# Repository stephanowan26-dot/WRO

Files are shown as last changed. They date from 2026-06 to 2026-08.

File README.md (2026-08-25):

# Ingeniería de Materiales — WRO Future Engineers 2026

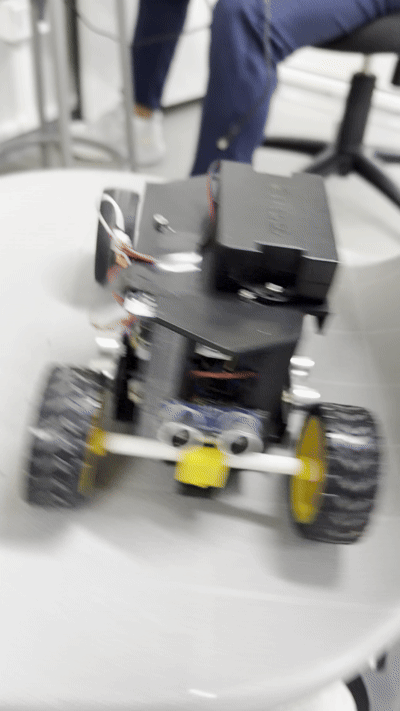
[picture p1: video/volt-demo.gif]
Volt en acción


**TEAM VOLT** — Lima, Perú — WRO Future Engineers 2026

Este repositorio documenta todo el proceso de ingeniería detrás de **"Volt"**, nuestro vehículo autónomo para la competencia WRO Future Engineers 2026: desde los primeros prototipos de cada componente hasta el modelo y código final de competencia.

---

## Tabla de Contenidos

1. [El Equipo](#el-equipo)
2. [Resumen del Vehículo](#resumen-del-vehículo)
3. [Contenido del Repositorio](#contenido-del-repositorio)
4. [Del Prototipo al Modelo Final](#del-prototipo-al-modelo-final)
5. [Arquitectura de Hardware](#arquitectura-de-hardware)
6. [Arquitectura de Software](#arquitectura-de-software)
7. [Errores que Encontramos y Cómo los Resolvimos](#errores-que-encontramos-y-cómo-los-resolvimos)
8. [Videos de Rendimiento](#videos-de-rendimiento)
9. [Instrucciones de Armado](#instrucciones-de-armado)
10. [Créditos](#créditos)
11. [Mejoras Futuras Posibles](#mejoras-futuras-posibles)

---

## El Equipo

**TEAM VOLT**

| Miembro | Edad |
|---|---|
| Carlos Jorge Rojas Ruiz | 17 |
| Stephano Wan Rong | 18 |
| Aadidev Nappanveetil Akhilesh | 17 |

<table>
  <tr>
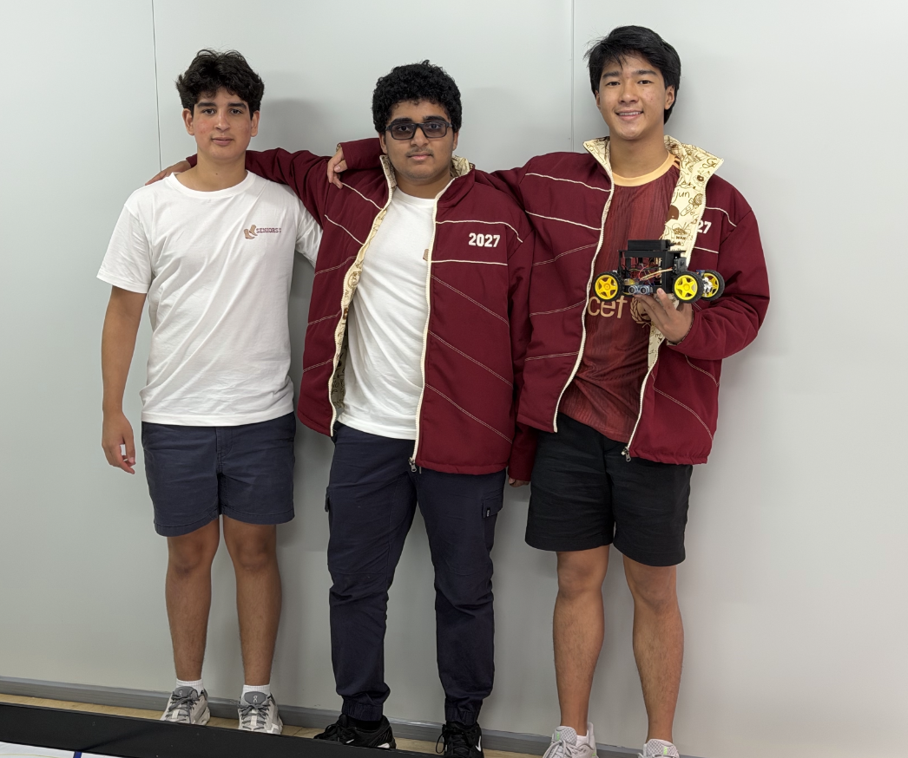
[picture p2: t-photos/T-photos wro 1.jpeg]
    <td align="center"><strong>Foto oficial</strong><br></td>
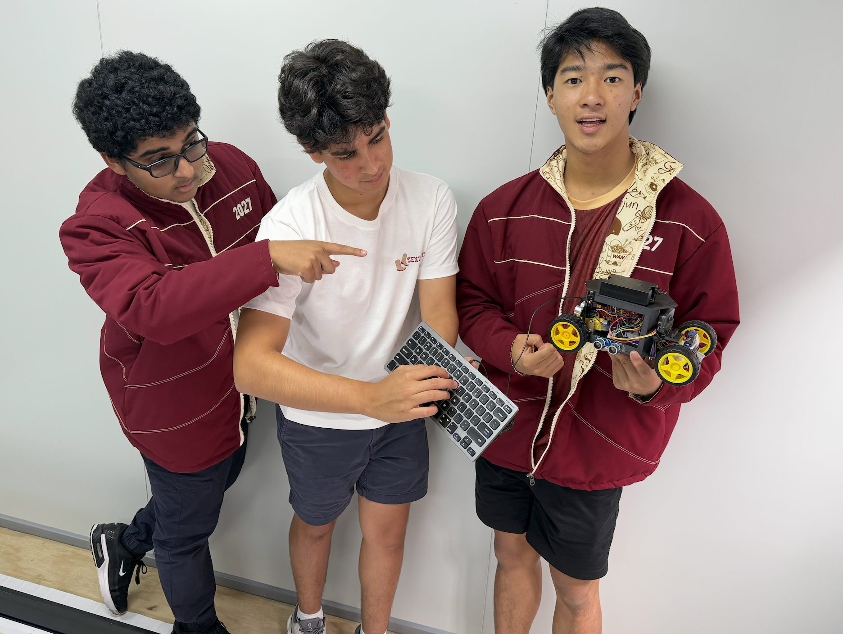
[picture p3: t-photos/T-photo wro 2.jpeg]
    <td align="center"><strong>Foto del equipo</strong><br></td>
  </tr>
</table>

---

## Resumen del Vehículo

"Volt" es un vehículo autónomo de cuatro ruedas, con tracción trasera y dirección delantera por servomotor, diseñado para navegar de forma completamente independiente un circuito de 3x3 metros, detectar y esquivar pilares de colores, y completar 3 vueltas de manera precisa y repetible, sin ninguna intervención humana.

El nombre "Volt" refleja la energía con la que el equipo abordó cada etapa: diseño mecánico, integración de sensores y programación del comportamiento autónomo.

**Dimensiones y peso** (dentro de las reglas de WRO 2026):
- Dimensiones máximas: 300 x 200 mm de planta, 300 mm de altura
- Peso total aproximado: bajo 1.5 kg

---

## Contenido del Repositorio

| Carpeta | Contenido |
|---|---|
| [`t-photos`](t-photos) | Fotos del equipo |
| [`v-photos`](v-photos) | Fotos del vehículo — prototipo y versión final, desde todos los lados |
| [`video`](video) | Enlaces a los videos de rendimiento en YouTube (Open y Obstacle Challenge) |
| [`schemes`](schemes) | Diagrama esquemático de los componentes electromecánicos y sus conexiones |
| [`src`](src) | Todo el código de control — desde prototipos individuales hasta el software final |
| [`models`](models) | Archivos STL para impresión 3D — chasis, ejes, soportes |
| [`material`](material) | Lista completa de materiales usados en el robot |

**Lee el README.md de cada carpeta para más detalle.**

---

## Del Prototipo al Modelo Final

Nuestro desarrollo fue iterativo: probamos cada componente por separado antes de integrarlo, y el chasis, el código y las fotos del vehículo pasaron por varias versiones hasta llegar al modelo final de competencia.

### Galería: Prototipo vs. Final

<table>
  <tr>
    <td align="center" colspan="2"><strong>Chasis</strong></td>
  </tr>
  <tr>
    <td align="center">Prototipo<br><em>(<a href="models/Prototype%20Chassis.stl">Prototype Chassis.stl</a>)</em></td>
    <td align="center">Final<br><em>(<a href="models/WRO%20Volt%20Chasis.stl">WRO Volt Chasis.stl</a>)</em></td>
  </tr>
  <tr>
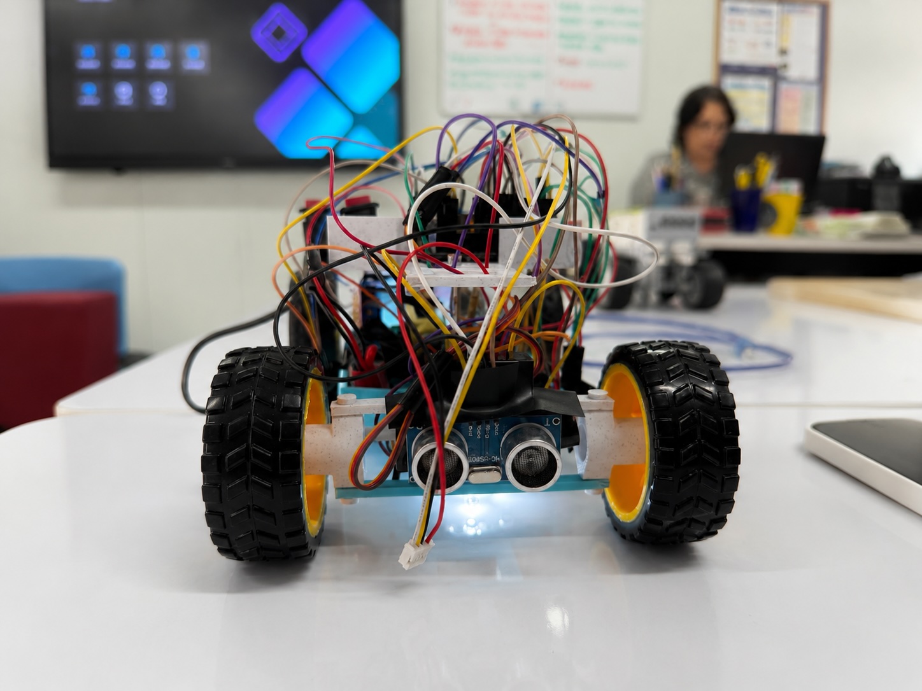
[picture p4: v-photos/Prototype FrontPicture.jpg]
    <td align="center"></td>
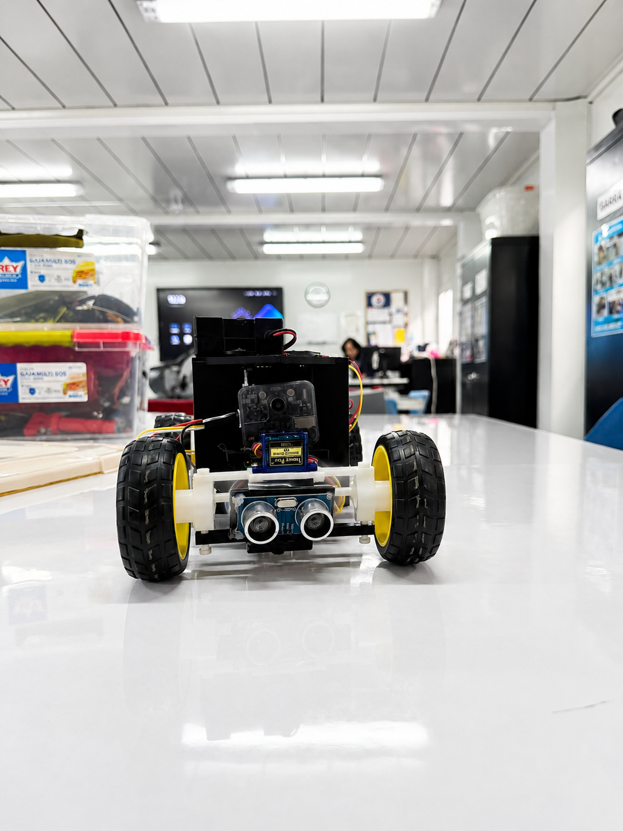
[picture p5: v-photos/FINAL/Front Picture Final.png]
    <td align="center"></td>
  </tr>
  <tr>
    <td align="center"></td>
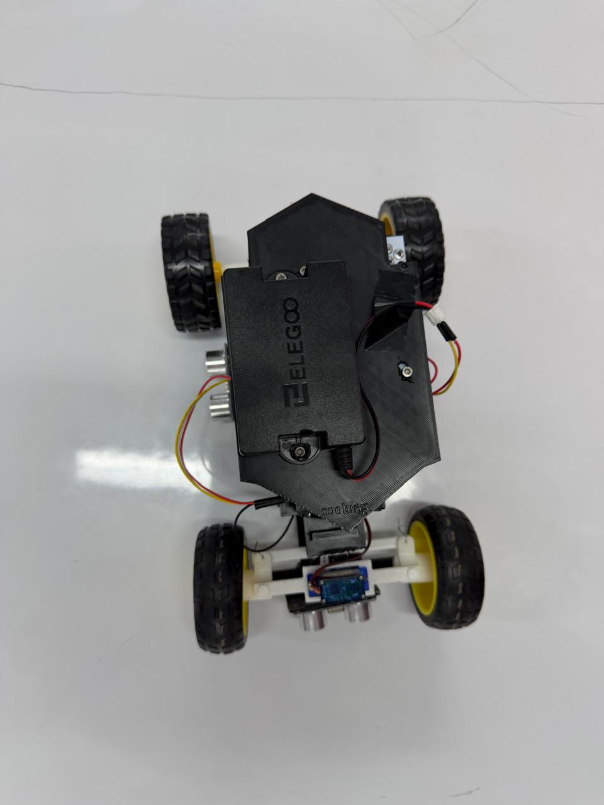
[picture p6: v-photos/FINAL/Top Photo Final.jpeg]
    <td align="center"></td>
  </tr>
  <tr>
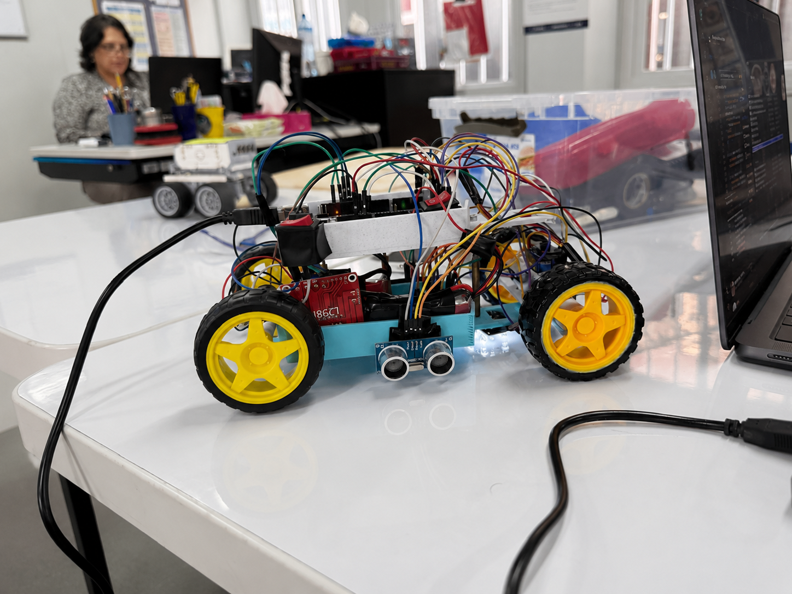
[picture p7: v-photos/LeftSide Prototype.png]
    <td align="center"></td>
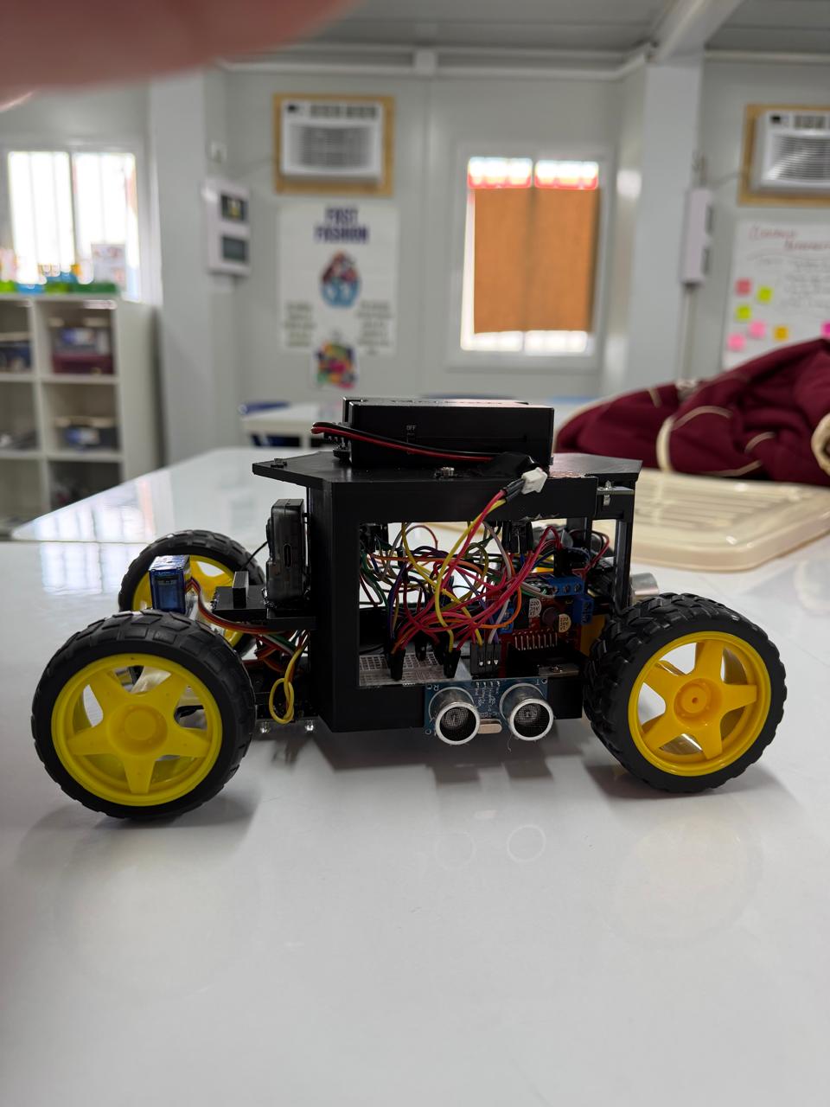
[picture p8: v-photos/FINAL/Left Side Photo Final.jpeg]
    <td align="center"></td>
  </tr>
  <tr>
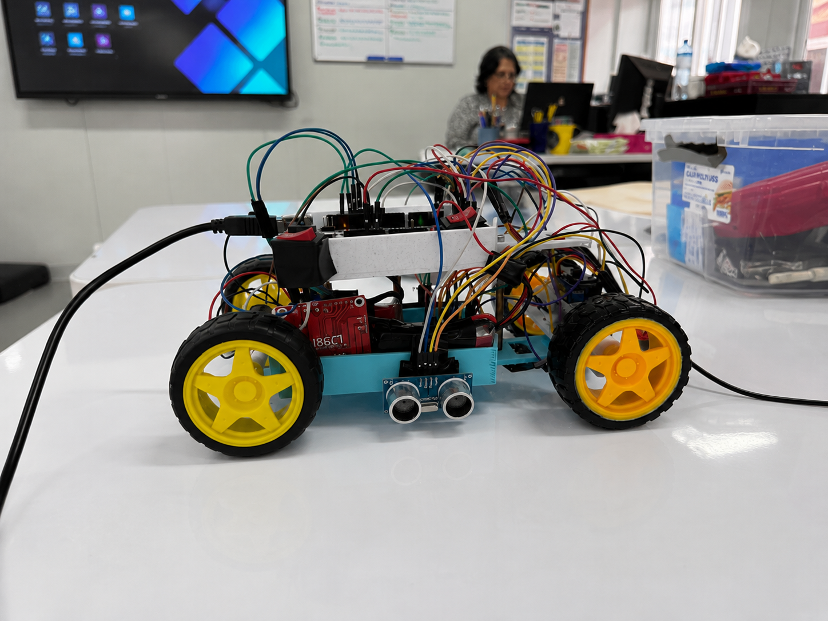
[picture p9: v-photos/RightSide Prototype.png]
    <td align="center"></td>
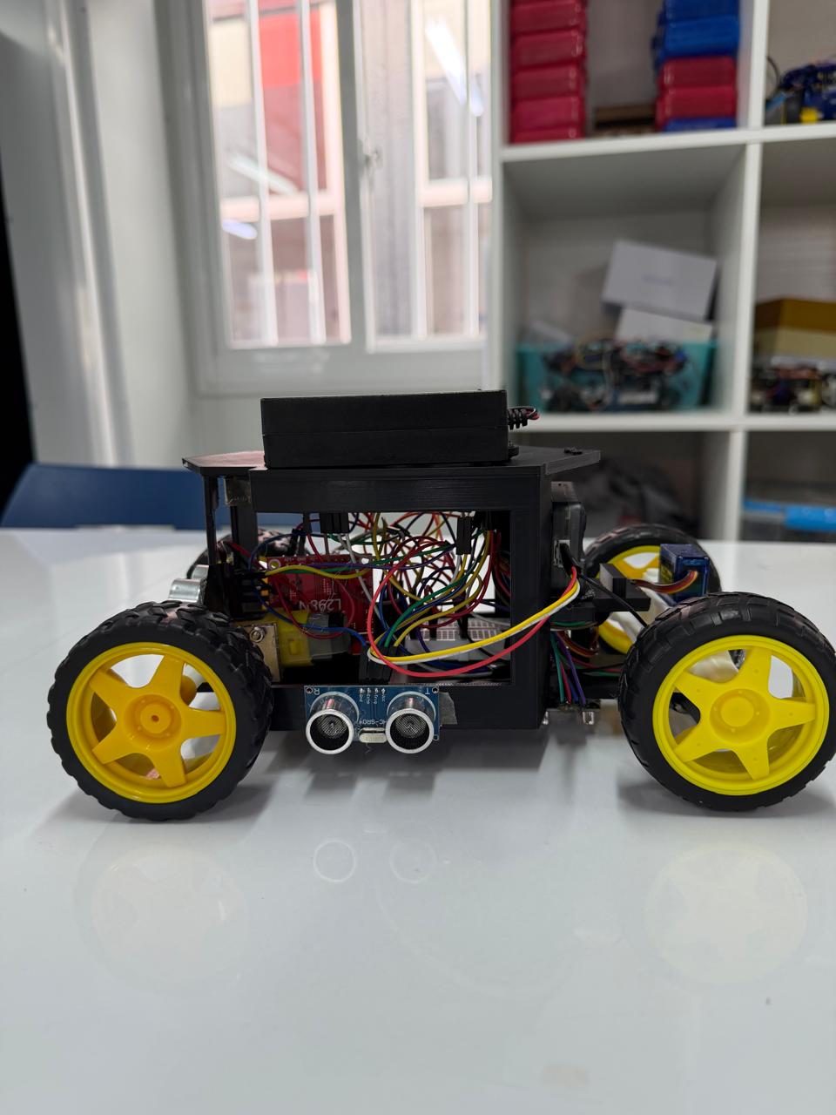
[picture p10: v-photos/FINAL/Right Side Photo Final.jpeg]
    <td align="center"></td>
  </tr>
</table>

### Línea de Tiempo del Desarrollo

| Etapa | Qué hicimos |
|---|---|
| **1. Pruebas de componentes individuales** ([`src`](src): `Prototype Motor Test`, `Prototype Ultrasonic Code`) | Código mínimo para confirmar que cada sensor y motor funcionaba por separado antes de integrarlo al resto del sistema. |
| **2. Primer código de conducción** ([`Prototype 3 Laps (Open Challenge) Code`](src/Prototype%203%20Laps%20%28Open%20Challenge%29%20Code)) | Primera versión capaz de dar vueltas completas al circuito, usada para probar la lógica de giro y de conteo de vueltas. |
| **3. Prueba de esquinas sin interferencia** (base de [`Final Open Challenge.ino`](src/Final%20Open%20Challenge.ino)) | Detectamos y arreglamos el problema de cross-talk entre los dos sensores ultrasónicos (ver sección de errores). |
| **4. Código Pre-Final** ([`Pre-Final Code 1`](src/Pre-Final%20Code%201)) | Integración de las correcciones anteriores en una versión más cercana a la de competencia. |
| **5. Código final — Open Challenge** ([`Final Open Challenge.ino`](src/Final%20Open%20Challenge.ino)) | Detección automática de dirección, cooldown entre esquinas y parada automática tras 12 esquinas (3 vueltas). |
| **6. Código final — Obstacle Challenge** ([`Final Obstacle Challenge.ino`](src/Final%20Obstacle%20Challenge.ino)) | Se añade la maniobra de salida de estacionamiento, detección de dirección por pared pegada, y evasión de pilares con pausa a media esquina para revisar la cámara. |

---

## Arquitectura de Hardware

### Controlador Principal

El cerebro del vehículo es un **Arduino Mega 2560**, elegido por su cantidad de pines digitales y su compatibilidad con las librerías de motores, servos y la cámara Sentry Vision 2.

### Sistema de Tracción

Motor **DC con caja reductora**, controlado por el driver **L298N**:

| Conexión | Pin |
|---|---|
| ENA (velocidad PWM) | 12 |
| IN1 | 11 |
| IN2 | 10 |
| VS (+) | Batería principal |
| GND | Tierra común |

### Sistema de Dirección

Servomotor **SG90** en el pin **9**, que mueve ambas ruedas delanteras mediante un varillaje mecánico. El servo se centra como primera operación absoluta en el `setup()` (con un delay de 1000ms) para evitar cualquier deriva al encender el vehículo.

| Ángulo | Open Challenge | Obstacle Challenge |
|---|:---:|:---:|
| Centro | 93° | 94° |
| Máximo izquierda | 46° | 46° |
| Máximo derecha | 140° | 140° |

### Sensores Ultrasónicos — HC-SR04

Usamos **dos sensores ultrasónicos**, uno a cada lado del vehículo, para detectar la apertura del corredor en cada esquina:

| Sensor | Trig | Echo |
|---|:---:|:---:|
| Izquierdo | 24 | 22 |
| Derecho | 50 | 52 |

El umbral de detección de esquina es **92 cm**: cuando la distancia lateral supera ese valor, el corredor interior se abrió y es momento de girar.

### Cámara de Visión — Sentry Vision 2 (Tosee Intelligence)

Comunicada por **I2C** (pines por defecto del Mega: SDA 20, SCL 21), detecta blobs de color entrenados para reconocer los pilares del Obstacle Challenge:

- **Label 13** → Pilar rojo → el robot lo pasa por la izquierda
- **Label 14** → Pilar verde → el robot lo pasa por la derecha

### Sistema de Alimentación

Una sola **batería Elegoo 2000mAh 7.4V**, distribuida por un riel de breadboard:

- Batería (+) → L298N VS y Arduino VIN
- Batería (−) → L298N GND y Arduino GND (tierra común)

El regulador interno del Arduino Mega convierte los 7.4V a 5V para los sensores.

Ver el diagrama completo en [`schemes/Circuit Final.png`](<schemes/Circuit%20Final.png>).

---

## Arquitectura de Software

Todo el software está escrito en **C++ para Arduino IDE** ([`src`](src)). Ambos programas finales comparten la misma base de lectura de sensores y control de motor, pero cada uno resuelve un desafío distinto.

### Final Open Challenge

[`Final Open Challenge.ino`](src/Final%20Open%20Challenge.ino) navega el circuito usando solo los dos sensores ultrasónicos:

- **Detección automática de dirección:** en la primera esquina detectada, el robot decide si el circuito es CW o CCW y desactiva el sensor opuesto por el resto de la carrera — evita giros incorrectos por lecturas cruzadas.
- **Giro por tiempo mínimo (875ms):** al detectar una esquina, el servo gira y se mantiene ese tiempo mínimo antes de volver a evaluar, evitando abandonar el giro por un falso positivo.
- **Cooldown de 1500ms** entre esquinas, para no re-detectar el mismo hueco dos veces.
- **Parada automática:** cuenta los giros (esquinas) completados; al llegar a **12** (3 vueltas × 4 esquinas), espera 900ms y se detiene por completo.

### Final Obstacle Challenge

[`Final Obstacle Challenge.ino`](src/Final%20Obstacle%20Challenge.ino) toma la misma base de navegación y agrega:

- **Detección de dirección al arrancar:** revisa qué pared está pegada al robot (< 10cm) para saber si debe salir del estacionamiento en sentido CW o CCW.
- **Maniobra de salida de estacionamiento:** secuencia de 3 fases (reversa, avance, avance lento) calibrada para cada sentido.
- **Esquinas con revisión de pilar a media vuelta:** el robot gira la primera mitad, se detiene 600ms para consultar la cámara, y según lo que detecta (pilar rojo, verde, o nada) completa el giro con una corrección distinta.
- **Ajuste en línea recta:** si detecta un pilar fuera de una esquina, hace un pequeño barrido de dirección para esquivarlo sin frenar.
- **Parada automática:** igual que el Open Challenge, cuenta esquinas y se detiene tras 12, con 500ms de espera.

---

## Errores que Encontramos y Cómo los Resolvimos

### 1. Interferencia (cross-talk) entre los sensores ultrasónicos

Al hacer sonar los dos sensores HC-SR04 seguidos, uno captaba el eco del otro, produciendo una lectura falsa de ~57cm justo en el hueco que debía activar el giro — el robot no doblaba cuando debía. **Solución:** una vez que la dirección del circuito queda fijada, el sensor opuesto se desactiva por completo y solo se lee el sensor del lado activo, eliminando la interferencia.

### 2. El conteo de vueltas por sensor de color resultó innecesario

Durante el desarrollo probamos y calibramos un sensor de color **TCS3200** (ver [`material`](material)) para contar las líneas naranjas del circuito y así saber cuándo detenerse. En la versión final decidimos reemplazar ese método: contar directamente las esquinas detectadas por los sensores ultrasónicos (12 esquinas = 3 vueltas) es más simple, no depende de la calibración de color bajo distintas luces, y usa un sensor que el robot ya necesitaba de todas formas.

### 3. Varias iteraciones de chasis antes del diseño final

Probamos e imprimimos varias piezas de chasis descargadas y modificadas antes de definir el diseño propio. Los archivos de esas iteraciones descartadas fueron eliminados del repositorio y solo se conservan el [`Prototype Chassis.stl`](models/Prototype%20Chassis.stl) y el diseño final, [`WRO Volt Chasis.stl`](models/WRO%20Volt%20Chasis.stl).

### 4. Lista de materiales incorrecta

La primera versión de nuestra lista de materiales ([`material`](material)) tenía componentes que en realidad no usamos (batería LiPo genérica, portapilas 18650, indicador de voltaje LED, sistema Ackermann como ítem aparte). La corregimos para reflejar exactamente lo que lleva "Volt": batería Elegoo 2000mAh 7.4V, chasis impreso en 3D, ruedas, protoboard e interruptor.

### 5. Recalibración de ángulos del servo

Entre versiones intermedias y la final ajustamos el centro del servo (de 90° a 93°/94° según el desafío) y el ángulo máximo hacia la izquierda (de 40° a 46°) para corregir una leve asimetría en el varillaje de dirección detectada durante las pruebas físicas.

---

## Videos de Rendimiento

| Desafío | Video |
|---|---|
| Open Challenge | [Ver en YouTube](https://www.youtube.com/shorts/3S9T03eFTFk) |
| Obstacle Challenge | [Ver en YouTube](https://www.youtube.com/watch?v=1XT1xbffeuU) |

Más detalles en [`video/README.md`](video/README.md).

---

## Instrucciones de Armado

1. **Lista de materiales** — reúne todos los componentes antes de empezar: [`material/`](material)
2. **Impresión 3D** — imprime las piezas del chasis y soportes con cualquier impresora compatible con STL: [`models/`](models)
3. **Conexiones eléctricas** — sigue el diagrama esquemático para las conexiones entre Arduino, driver, sensores y batería: [`schemes/Circuit Final.png`](<schemes/Circuit%20Final.png>)
4. **Cargar el código** — sube [`Final Open Challenge.ino`](src/Final%20Open%20Challenge.ino) o [`Final Obstacle Challenge.ino`](src/Final%20Obstacle%20Challenge.ino) según el desafío, usando Arduino IDE con las librerías `Servo.h`, `Wire.h` y `Sentry.h` (esta última de Tosee Intelligence).

---

## Créditos

- **Chasis:** basado en [Simple Arduino RC CAR](https://www.thingiverse.com/thing:6667669) por **T_Lab** (Thingiverse, junio 2024), usado como referencia y modificado para adaptarlo a los componentes y dimensiones de "Volt". Ver [`models/README.md`](models/README.md#créditos).

---

## Mejoras Futuras Posibles

- **Distancia lateral con más de un sensor por lado:** un segundo sensor por lado ayudaría a confirmar esquinas y reducir falsos positivos sin depender solo del cooldown por tiempo.
- **Encoder en el motor de tracción:** permitiría medir distancia recorrida real en vez de depender únicamente de tiempos fijos de giro.
- **PCB en vez de breadboard:** reduciría el riesgo de cables sueltos y mejoraría la fiabilidad de las conexiones durante el transporte y la competencia.
- **Rangos de color dinámicos:** si en el futuro se retoma el sensor de color, ajustar los umbrales de detección automáticamente según la luz ambiental lo haría más confiable entre distintos escenarios.

---

*Desarrollado por TEAM VOLT — WRO Future Engineers 2026 — Lima, Perú*

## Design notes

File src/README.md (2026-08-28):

# Control Software

This directory contains the control software developed by **Volt** for the WRO 2026 Future Engineers competition.

The code documents the evolution of our autonomous vehicle, from the first hardware tests to the final competition programs. It includes prototypes used to test individual components, such as the motors, servo, ultrasonic sensors, and color sensor, as well as the complete autonomous driving algorithms.

The main functions implemented in the final software include:

- Autonomous vehicle movement and steering
- Ultrasonic wall and obstacle detection
- Continuous wall-centering corrections
- Automatic corner detection and turning
- TCS3200 color sensor integration
- Lap and line counting
- Obstacle avoidance
- Automatic stopping after completing the required laps

The different files in this directory are preserved to show the development and testing process that led to the final version uploaded to the robot.

---

## Software de Control

Este directorio contiene el software de control desarrollado por **Volt** para la competencia WRO 2026 Future Engineers.

Los códigos documentan la evolución de nuestro vehículo autónomo, desde las primeras pruebas de hardware hasta los programas finales utilizados en competencia. Se incluyen prototipos creados para probar individualmente componentes como los motores, el servomotor, los sensores ultrasónicos y el sensor de color, además de los algoritmos completos de conducción autónoma.

Las principales funciones implementadas en el software final incluyen:

- Movimiento y dirección autónoma del vehículo
- Detección de paredes y obstáculos mediante sensores ultrasónicos
- Correcciones continuas para mantener el vehículo centrado
- Detección automática de esquinas y ejecución de giros
- Integración del sensor de color TCS3200
- Conteo de líneas y vueltas
- Evasión de obstáculos
- Detención automática al completar las vueltas requeridas

Los diferentes archivos de este directorio se conservan para mostrar el proceso de desarrollo, prueba e iteración que llevó al código final cargado en el robot.

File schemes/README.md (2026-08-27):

Electromechanical diagrams
====

This directory contains our schematic diagram in form PNG of the electronical components illustrating all the elements (Ultrasonicsensors, Servo motor for the axis, DC motors & Motor shield, Wheels, Microcontroller Arduino Mega, Piezzo buzzer) used in the vehicle and how they connect to each other on the mini breadboard. Our robot is powered by two 9V batteries, one for the axis and one for the wheels. We used cirkitdesigner to draw the schematic.

Este directorio contiene nuestro diagrama esquemático en formato PNG de los componentes electrónicos, que ilustra todos los elementos utilizados en el vehículo (sensores ultrasónicos, servo motor para el eje, motores DC y shield de motor, ruedas, microcontrolador Arduino Mega y zumbador piezoeléctrico), así como la forma en que se conectan entre sí en la mini breadboard. Nuestro robot está alimentado por dos baterías de 9V: una para el eje y otra para las ruedas. El diagrama fue dibujado utilizando Canva.

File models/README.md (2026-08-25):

Estos son los archivos para la **cortadora láser** y la **impresora 3D**.

1. **Axis Pin.stl** : Pin de eje — permite que una pieza gire libremente (a diferencia de un clavo/pin fijo)
2. **Nut.stl** : Tuerca
3. **Prototype Chassis.stl** : Modelo 3D del chasis (versión prototipo)
4. **Rear Axis.stl** : Eje trasero
5. **Servo Steering Axis Holder.stl** : Soporte del eje de dirección del servo
6. **Shaft for Wheels.stl** : Eje que sostiene las ruedas
7. **Steering Axis Rod 1.stl** : Varilla del eje de dirección
8. **WRO Volt Chasis.stl** : Modelo del chasis (versión final)
9. **Wheel Pin.stl** : Pin que sostiene la rueda en su lugar

---

## Créditos

El diseño del chasis se basó en **["Simple Arduino RC CAR"](https://www.thingiverse.com/thing:6667669)** por **T_Lab** (Thingiverse, junio 2024), que usamos como referencia y modificamos para adaptarlo a los componentes y dimensiones de "Volt".

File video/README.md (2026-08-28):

# Videos de Rendimiento del Vehículo

## Open Challenge

YouTube: https://www.youtube.com/shorts/3S9T03eFTFk

El video muestra al vehículo conduciendo de manera autónoma durante el Open Challenge.

## Obstacle Challenge

YouTube: https://www.youtube.com/watch?v=1XT1xbffeuU

El video muestra al vehículo conduciendo de manera autónoma durante el Obstacle Challenge.

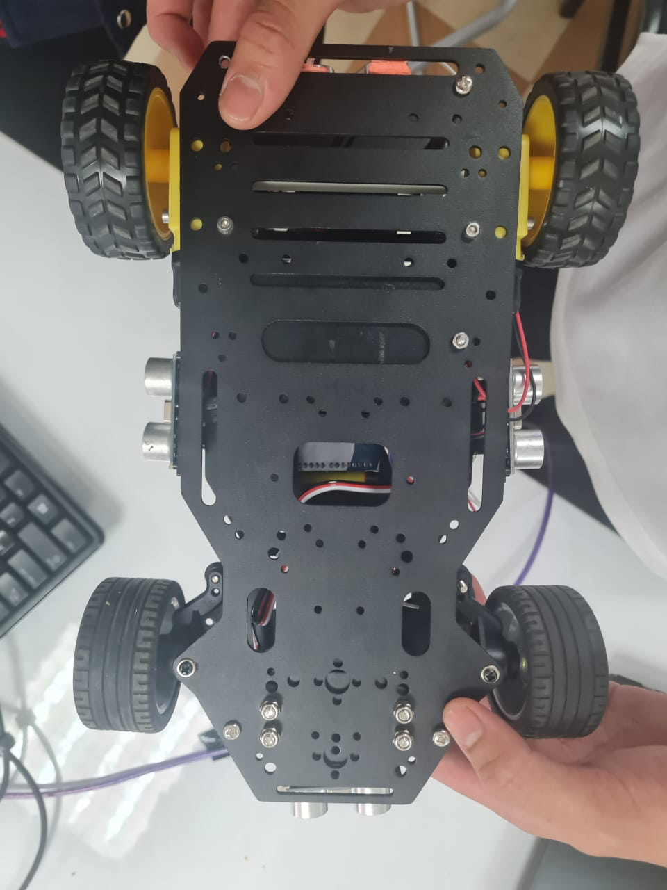
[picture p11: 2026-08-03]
v-photos/BottomPhoto.png

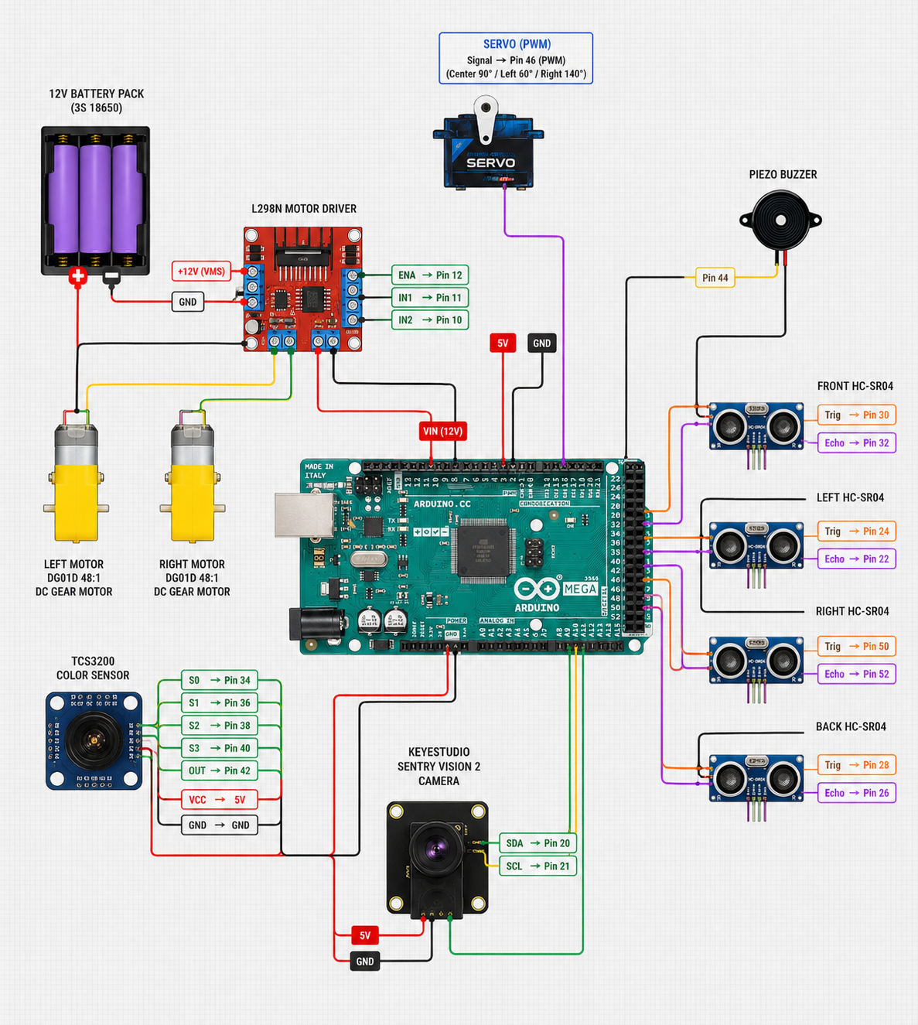
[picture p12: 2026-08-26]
schemes/Circuit Final.png

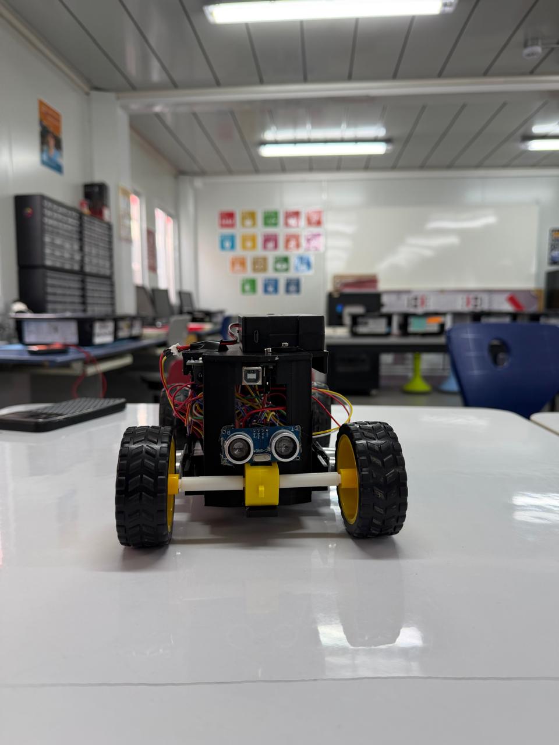
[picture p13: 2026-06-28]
v-photos/FINAL/Back Photo Final.jpeg

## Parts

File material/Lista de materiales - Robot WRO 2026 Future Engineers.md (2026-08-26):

**Lista de materiales \- Robot WRO 2026 Future Engineers**

* Arduino Mega 2560  
* Módulo puente H L298N (driver de motor)  
* Servo motor SG90  
* Motor DC con reductor (para tracción)  
* Cámara Sentry Vision 2 (Tosee Intelligence)  
* Sensor de color TCS3200  
* 4x Sensores ultrasónicos HC-SR04

**Alimentación**

* Batería Elegoo 2000mAh 7.4V  
* Chasis del robot (impreso 3D)  
* Ruedas

**Conexiones**

* Protoboard o breadboard  
* Interruptor/switch de encendido (2 pines)

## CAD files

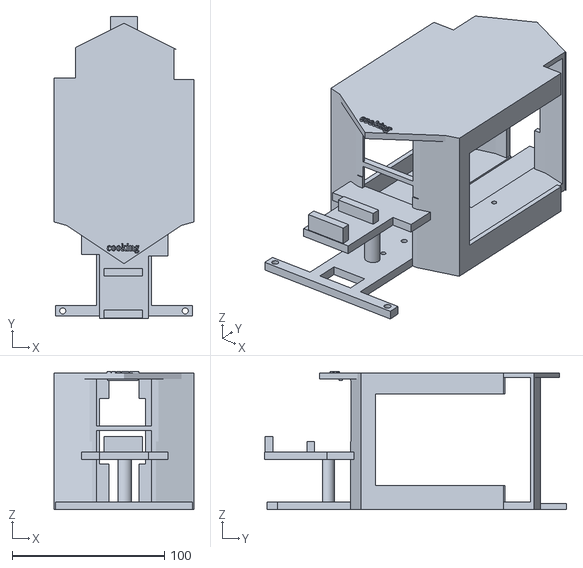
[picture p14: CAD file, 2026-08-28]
models/WRO Volt Chasis.stl
92.0 x 198.5 x 91.0

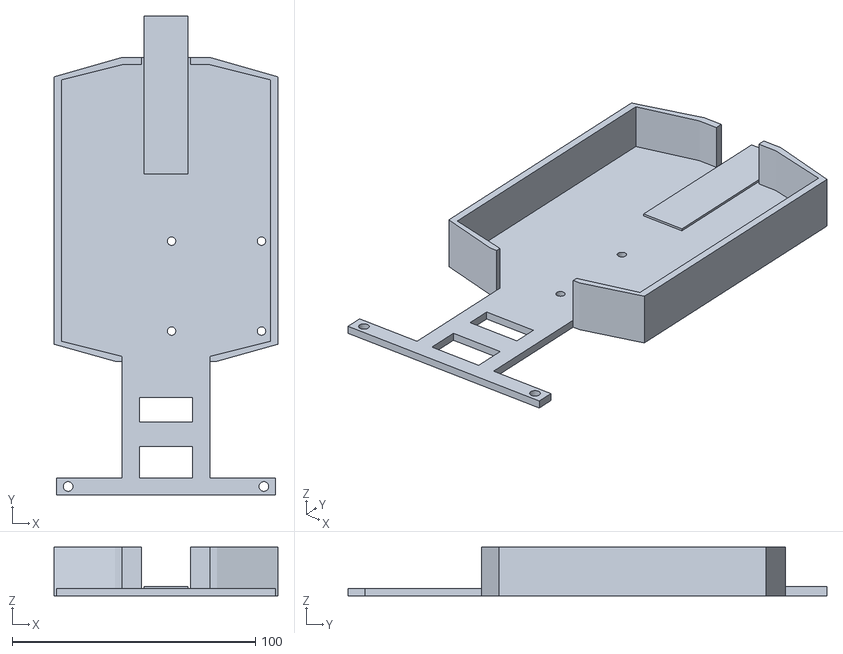
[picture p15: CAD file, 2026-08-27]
models/Prototype Chassis.stl
92.0 x 197.0 x 20.0

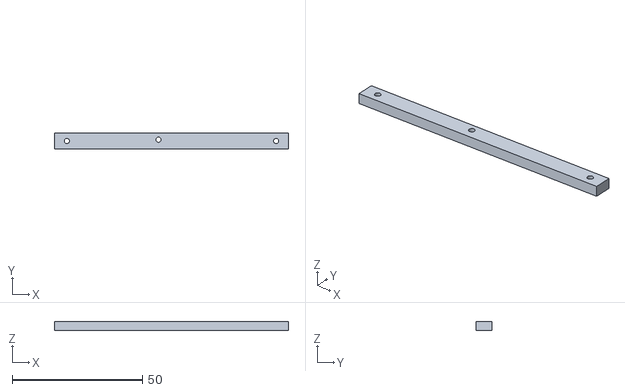
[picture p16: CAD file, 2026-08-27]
models/Steering Axis Rod 1.stl
90.0 x 6.00 x 3.40

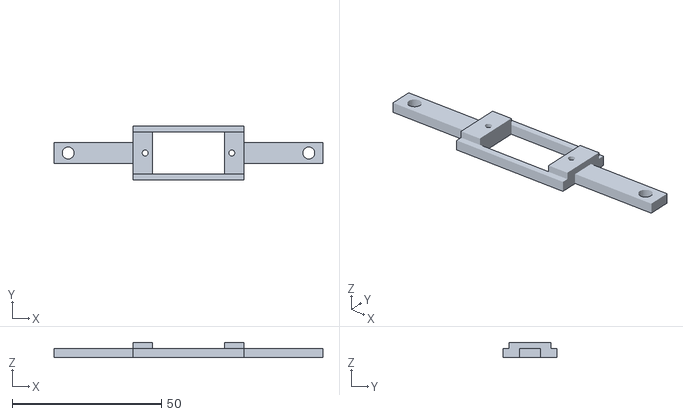
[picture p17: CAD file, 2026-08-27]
models/Servo Steering Axis Holder.stl
90.0 x 18.0 x 5.00

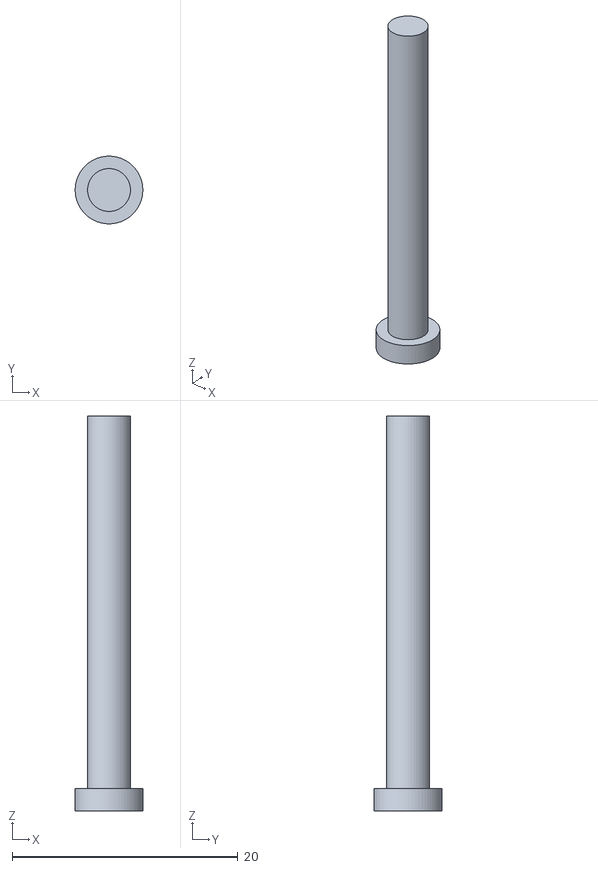
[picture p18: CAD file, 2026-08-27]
models/Axis Pin.stl
6.00 x 5.99 x 35.0

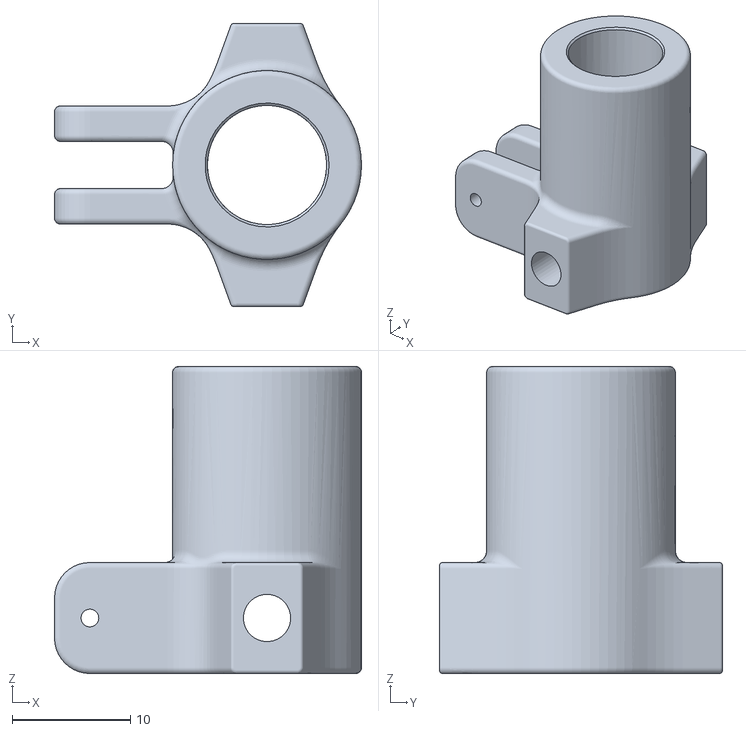
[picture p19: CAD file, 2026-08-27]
models/Shaft for WHeels.stl
26.0 x 24.0 x 26.0

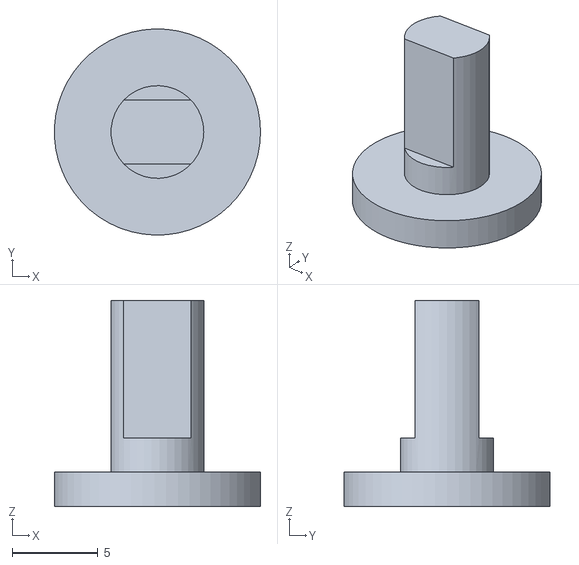
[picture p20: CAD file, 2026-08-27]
models/Wheel Pin.stl
12.0 x 12.0 x 12.0

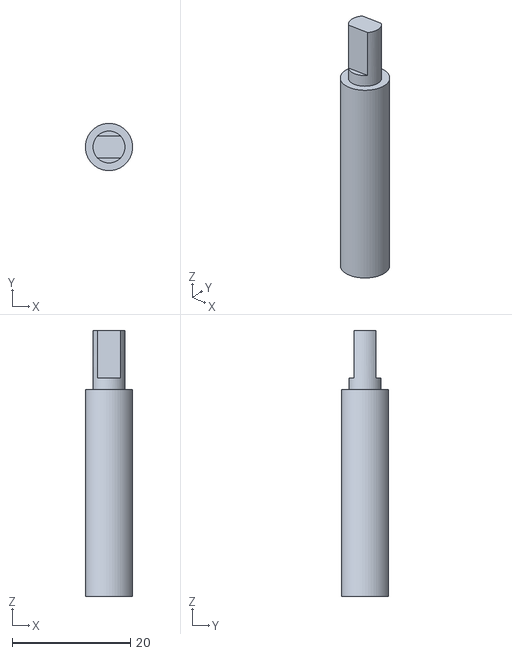
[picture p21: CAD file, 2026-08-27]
models/Rear Axis .stl
8.00 x 8.00 x 45.0

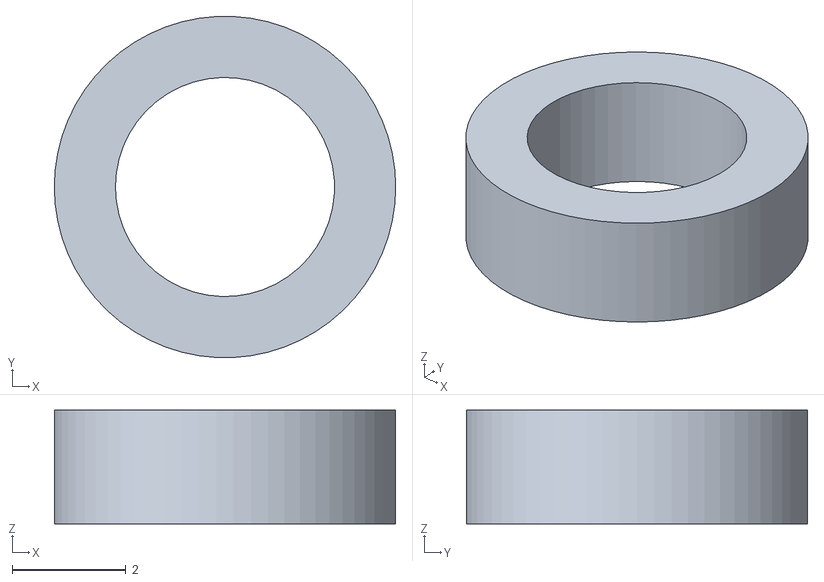
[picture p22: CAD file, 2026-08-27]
models/Nut.stl
6.00 x 5.99 x 2.00

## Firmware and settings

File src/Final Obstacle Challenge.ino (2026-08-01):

// ═══════════════════════════════════════════════════════
//  WRO 2026 - DESAFÍO DE OBSTÁCULOS - FINAL
//  1. Arranque: detectar dirección (pared pegada < 10cm)
//  2. Ejecutar maniobra de salida del estacionamiento
//  3. Correr el desafío de obstáculos con detección de pilar a media esquina
//     El robot PAUSA a media vuelta para revisar la cámara
//     ROJO  → deriva a la derecha (>90) → corrección barrido IZQUIERDA
//     VERDE → deriva a la izquierda (<90) → corrección barrido DERECHA
// ═══════════════════════════════════════════════════════

#include <Servo.h>
#include <Sentry.h>
#include <Wire.h>

typedef Sentry2 Sentry;
Sentry sentry;

// ── Servo ────────────────────────────────────────────────
Servo steeringServo;
#define SERVO_PIN          9
#define SERVO_CENTER       94
#define SERVO_LEFT         46
#define SERVO_RIGHT        140
#define SERVO_SLIGHT_LEFT  60
#define SERVO_SLIGHT_RIGHT 120

// ── Ángulos de pilar a media esquina ─────────────────────
#define CORNER_MID_RIGHT   115
#define CORNER_MID_LEFT     70

// ── Ángulos y tiempos de corrección ──────────────────────
#define CORNER_CORRECT_ANGLE_LEFT    50
#define CORNER_CORRECT_ANGLE_RIGHT  130
#define CORNER_CORRECT_TIME_LEFT    400
#define CORNER_CORRECT_TIME_RIGHT   400

// ── Motor ────────────────────────────────────────────────
#define ENA  12
#define IN1  11
#define IN2  10
#define SPEED_STRAIGHT  110
#define SPEED_CURVE     150
#define SPEED_TWEAK     130
#define SPEED_EXIT      180
#define SPEED_PHASE3    150

// ── Ultrasónicos ─────────────────────────────────────────
#define TRIG_L  24
#define ECHO_L  22
#define TRIG_R  50
#define ECHO_R  52

// ── Configuración: Esquina ───────────────────────────────
#define CORNER_DIST         92
#define MIN_TURN_TIME_CCW  1800
#define MIN_TURN_TIME_CW   1800
#define HALF_TURN_TIME      1000   // ms - primera mitad del giro
#define SECOND_HALF_TIME    600   // ms - segunda mitad del giro (ajustable)
#define MID_PAUSE_TIME     600   // ms - pausa a media vuelta para revisar cámara
#define CORNER_COOLDOWN    1500
#define EXIT_COOLDOWN       800
#define PING_GAP            60

// ── Contador de giros - parar después de TOTAL_TURNS_TO_STOP esquinas ──
#define TOTAL_TURNS_TO_STOP      12  // número de esquinas antes de parar
#define STOP_DELAY_AFTER_LAST_TURN_MS 500  // ms - esperar esto después de
                                             // la última esquina antes de la parada total

// ── Detección de dirección al arrancar ───────────────────
#define WALL_STUCK_DIST    10

// ── Salida de estacionamiento CW ─────────────────────────
#define CW_REVERSE_LEFT_TIME    450
#define CW_FWD_RIGHT_TIME      1100
#define CW_FWD_LEFT_TIME       1500

// ── Salida de estacionamiento CCW ────────────────────────
#define CCW_REVERSE_RIGHT_TIME  450
#define CCW_FWD_LEFT_TIME      1100
#define CCW_FWD_RIGHT_TIME     1500

#define PRE_TURN_TIME    300

// ── Ajuste pilar rojo (línea recta) ──────────────────────
#define RED_TWEAK_RIGHT_TIME    1000
#define RED_TWEAK_LEFT_TIME     800

// ── Ajuste pilar verde (línea recta) ─────────────────────
#define GREEN_TWEAK_LEFT_TIME   1000
#define GREEN_TWEAK_RIGHT_TIME  800

#define PILLAR_COOLDOWN         2000

// ── Etiquetas de blob ──────────────────────────────────────
#define LABEL_RED    13
#define LABEL_GREEN  14

// ── Estado de dirección ──────────────────────────────────
enum Direction { UNKNOWN, CCW, CW };
Direction direction = UNKNOWN;

unsigned long lastCornerTime = 0;
unsigned long lastPillarTime = 0;
int turnCount = 0;
bool deadStopped = false;

// ─────────────────────────────────────────────────────────
//  Leer distancia ultrasónica (cm)
// ─────────────────────────────────────────────────────────
float readDistance(int trigPin, int echoPin) {
  digitalWrite(trigPin, LOW);
  delayMicroseconds(2);
  digitalWrite(trigPin, HIGH);
  delayMicroseconds(10);
  digitalWrite(trigPin, LOW);
  long duration = pulseIn(echoPin, HIGH, 30000);
  if (duration == 0) return 999;
  float dist = duration * 0.034 / 2.0;
  if (dist > 400) return 999;
  return dist;
}

// ─────────────────────────────────────────────────────────
//  Motor
// ─────────────────────────────────────────────────────────
void driveForward(int speed) {
  analogWrite(ENA, speed);
  digitalWrite(IN1, HIGH);
  digitalWrite(IN2, LOW);
}

void driveBackward(int speed) {
  analogWrite(ENA, speed);
  digitalWrite(IN1, LOW);
  digitalWrite(IN2, HIGH);
}

void stopMotor() {
  digitalWrite(ENA, LOW);
  digitalWrite(IN1, LOW);
  digitalWrite(IN2, LOW);
}

// ─────────────────────────────────────────────────────────
//  Revisar pilares - retorna 0=ninguno 1=rojo 2=verde
// ─────────────────────────────────────────────────────────
int checkPillars() {
  int detected = sentry.GetValue(Sentry::kVisionBlob, kStatus);
  if (detected > 0) {
    int label = sentry.GetValue(Sentry::kVisionBlob, kLabel, 1);
    int x     = sentry.GetValue(Sentry::kVisionBlob, kXValue, 1);
    if (label == LABEL_RED) {
      Serial.print("ROJO X:"); Serial.println(x);
      return 1;
    }
    else if (label == LABEL_GREEN) {
      Serial.print("VERDE X:"); Serial.println(x);
      return 2;
    }
  }
  return 0;
}

// ─────────────────────────────────────────────────────────
//  Giro en esquina con revisión a media vuelta (PAUSA en el punto medio)
// ─────────────────────────────────────────────────────────
void doTurn(int servoAngle, int turnTime) {
  Serial.println("ESQUINA DETECTADA - GIRANDO!");

  // Fase A: primera mitad al ángulo normal
  steeringServo.write(servoAngle);
  driveForward(SPEED_CURVE);
  delay(HALF_TURN_TIME);

  // PAUSA para revisar la cámara claramente
  Serial.println("Pausando para revisar pilar...");
  stopMotor();
  delay(MID_PAUSE_TIME);

  // Fase B: revisar cámara
  int pillar = checkPillars();

  if (pillar == 1) {
    // ROJO → deriva a la derecha por SECOND_HALF_TIME → corrige IZQUIERDA
    Serial.println("MEDIA-ESQUINA ROJO → deriva derecha + corrige IZQUIERDA");
    steeringServo.write(CORNER_MID_RIGHT);
    driveForward(SPEED_CURVE);
    delay(SECOND_HALF_TIME);

    steeringServo.write(CORNER_CORRECT_ANGLE_LEFT);
    driveForward(SPEED_TWEAK);
    delay(CORNER_CORRECT_TIME_LEFT);
  }
  else if (pillar == 2) {
    // VERDE → deriva a la izquierda por SECOND_HALF_TIME → corrige DERECHA
    Serial.println("MEDIA-ESQUINA VERDE → deriva izquierda + corrige DERECHA");
    steeringServo.write(CORNER_MID_LEFT);
    driveForward(SPEED_CURVE);
    delay(SECOND_HALF_TIME);

    steeringServo.write(CORNER_CORRECT_ANGLE_RIGHT);
    driveForward(SPEED_TWEAK);
    delay(CORNER_CORRECT_TIME_RIGHT);
  }
  else {
    // Sin pilar → completa el giro al ángulo original por SECOND_HALF_TIME
    steeringServo.write(servoAngle);
    driveForward(SPEED_CURVE);
    delay(SECOND_HALF_TIME);
  }

  steeringServo.write(SERVO_CENTER);
  lastCornerTime = millis();

  // ── Contador de giros ─────────────────────────────────
  turnCount++;
  Serial.print("CONTEO DE GIROS: ");
  Serial.println(turnCount);

  if (turnCount >= TOTAL_TURNS_TO_STOP) {
    delay(STOP_DELAY_AFTER_LAST_TURN_MS);
    stopMotor();
    steeringServo.write(SERVO_CENTER);
    deadStopped = true;
    Serial.println("PARADA TOTAL - se alcanzó el conteo de giros");
  }

  delay(300);
}

// ─────────────────────────────────────────────────────────
//  Ajuste pilar ROJO (detección en línea recta)
// ─────────────────────────────────────────────────────────
void doRedTweak() {
  Serial.println("=== AJUSTE ROJO ===");
  steeringServo.write(SERVO_SLIGHT_RIGHT);
  driveForward(SPEED_TWEAK);
  delay(RED_TWEAK_RIGHT_TIME);
  steeringServo.write(SERVO_SLIGHT_LEFT);
  driveForward(SPEED_TWEAK);
  delay(RED_TWEAK_LEFT_TIME);
  steeringServo.write(SERVO_CENTER);
  lastPillarTime = millis();
}

// ─────────────────────────────────────────────────────────
//  Ajuste pilar VERDE (detección en línea recta)
// ─────────────────────────────────────────────────────────
void doGreenTweak() {
  Serial.println("=== AJUSTE VERDE ===");
  steeringServo.write(SERVO_SLIGHT_LEFT);
  driveForward(SPEED_TWEAK);
  delay(GREEN_TWEAK_LEFT_TIME);
  steeringServo.write(SERVO_SLIGHT_RIGHT);
  driveForward(SPEED_TWEAK);
  delay(GREEN_TWEAK_RIGHT_TIME);
  steeringServo.write(SERVO_CENTER);
  lastPillarTime = millis();
}

// ─────────────────────────────────────────────────────────
//  Salida de estacionamiento CW
// ─────────────────────────────────────────────────────────
void parkingExitCW() {
  Serial.println("=== SALIDA DE ESTACIONAMIENTO CW ===");

  Serial.println("Fase 1: reversa IZQUIERDA");
  steeringServo.write(SERVO_LEFT);
  delay(PRE_TURN_TIME);
  driveBackward(SPEED_EXIT);
  delay(CW_REVERSE_LEFT_TIME);
  stopMotor();

  Serial.println("Fase 2: adelante DERECHA");
  steeringServo.write(SERVO_RIGHT);
  delay(PRE_TURN_TIME);
  driveForward(SPEED_EXIT);
  delay(CW_FWD_RIGHT_TIME);
  stopMotor();

  Serial.println("Fase 3: adelante IZQUIERDA (LENTO)");
  steeringServo.write(SERVO_LEFT);
  delay(PRE_TURN_TIME);
  driveForward(SPEED_PHASE3);
  delay(CW_FWD_LEFT_TIME);
  stopMotor();

  Serial.println("=== SALIDA COMPLETA ===");
}

// ─────────────────────────────────────────────────────────
//  Salida de estacionamiento CCW
// ─────────────────────────────────────────────────────────
void parkingExitCCW() {
  Serial.println("=== SALIDA DE ESTACIONAMIENTO CCW ===");

  Serial.println("Fase 1: reversa DERECHA");
  steeringServo.write(SERVO_RIGHT);
  delay(PRE_TURN_TIME);
  driveBackward(SPEED_EXIT);
  delay(CCW_REVERSE_RIGHT_TIME);
  stopMotor();

  Serial.println("Fase 2: adelante IZQUIERDA");
  steeringServo.write(SERVO_LEFT);
  delay(PRE_TURN_TIME);
  driveForward(SPEED_EXIT);
  delay(CCW_FWD_LEFT_TIME);
  stopMotor();

  Serial.println("Fase 3: adelante DERECHA (LENTO)");
  steeringServo.write(SERVO_RIGHT);
  delay(PRE_TURN_TIME);
  driveForward(SPEED_PHASE3);
  delay(CCW_FWD_RIGHT_TIME);
  stopMotor();

  Serial.println("=== SALIDA COMPLETA ===");
}

// ─────────────────────────────────────────────────────────
//  Detectar dirección según qué pared está pegada
// ─────────────────────────────────────────────────────────
Direction detectStartupDirection() {
  Serial.println("Detectando dirección de arranque...");
  int leftStuckCount  = 0;
  int rightStuckCount = 0;

  for (int i = 0; i < 5; i++) {
    float distL = readDistance(TRIG_L, ECHO_L);
    delay(PING_GAP);
    float distR = readDistance(TRIG_R, ECHO_R);

    Serial.print("I:"); Serial.print(distL);
    Serial.print(" D:"); Serial.println(distR);

    if (distL < WALL_STUCK_DIST) leftStuckCount++;
    if (distR < WALL_STUCK_DIST) rightStuckCount++;
    delay(500);
  }

  if (leftStuckCount > rightStuckCount) {
    Serial.println(">>> Pared izquierda pegada → CW");
    return CW;
  } else {
    Serial.println(">>> Pared derecha pegada → CCW");
    return CCW;
  }
}

// ─────────────────────────────────────────────────────────
//  Configuración
// ─────────────────────────────────────────────────────────
void setup() {
  steeringServo.attach(SERVO_PIN);
  steeringServo.write(SERVO_CENTER);
  delay(1000);

  Serial.begin(9600);

  pinMode(ENA, OUTPUT);
  pinMode(IN1, OUTPUT);
  pinMode(IN2, OUTPUT);
  stopMotor();

  pinMode(TRIG_L, OUTPUT); pinMode(ECHO_L, INPUT);
  pinMode(TRIG_R, OUTPUT); pinMode(ECHO_R, INPUT);

  Wire.begin();
  Serial.println("Conectando Sentry2...");
  while (SENTRY_OK != sentry.begin(&Wire)) {
    Serial.println("Esperando Sentry2...");
    delay(500);
  }
  sentry.VisionBegin(Sentry::kVisionBlob);
  Serial.println("Sentry2 listo!");

  Serial.println("WRO 2026 - Final Obstacle Challenge");

  direction = detectStartupDirection();

  if (direction == CW) {
    parkingExitCW();
  } else {
    parkingExitCCW();
  }

  lastCornerTime = millis() - CORNER_COOLDOWN + EXIT_COOLDOWN;
  Serial.println("ARRANCA! Desafío de obstáculos ON...");
}

// ─────────────────────────────────────────────────────────
//  Bucle principal
// ─────────────────────────────────────────────────────────
void loop() {

  // ── Parada total - detiene para siempre después de TOTAL_TURNS_TO_STOP ──
  if (deadStopped) {
    return;  // ya está parado, no hace nada más
  }

  float distL = 999;
  float distR = 999;

  if (direction == CCW) {
    distL = readDistance(TRIG_L, ECHO_L);
    Serial.print("I:"); Serial.print(distL);
    Serial.println(" D:OFF");
  } else {
    distR = readDistance(TRIG_R, ECHO_R);
    Serial.print("I:OFF");
    Serial.print(" D:"); Serial.println(distR);
  }

  bool cornerCooldownOk = (millis() - lastCornerTime > CORNER_COOLDOWN);
  bool pillarCooldownOk = (millis() - lastPillarTime > PILLAR_COOLDOWN);

  if (direction == CCW) {
    if (cornerCooldownOk && distL > CORNER_DIST) {
      doTurn(SERVO_LEFT, MIN_TURN_TIME_CCW);
      return;
    }
  }
  else if (direction == CW) {
    if (cornerCooldownOk && distR > CORNER_DIST) {
      doTurn(SERVO_RIGHT, MIN_TURN_TIME_CW);
      return;
    }
  }

  if (pillarCooldownOk) {
    int pillar = checkPillars();
    if (pillar == 1) {
      doRedTweak();
      return;
    }
    else if (pillar == 2) {
      doGreenTweak();
      return;
    }
  }

  steeringServo.write(SERVO_CENTER);
  driveForward(SPEED_STRAIGHT);
}

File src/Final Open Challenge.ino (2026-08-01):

// ═══════════════════════════════════════════════════════
//  WRO 2026 - DESAFÍO OPEN - FINAL
//  Detección automática de dirección - la primera esquina fija la dirección
//  CCW = detección de hueco con sensor IZQUIERDO
//  CW  = detección de hueco con sensor DERECHO
//  Sin conteo de vueltas - corre indefinidamente
//
//  ARREGLO DE INTERFERENCIA: una vez fijada la dirección, el
//  ultrasónico opuesto nunca se vuelve a activar. Dos sensores
//  pitando seguido dejan que uno capte el eco del otro, dando
//  una lectura falsa de ~57cm en el hueco que bloqueaba el giro.
// ═══════════════════════════════════════════════════════

#include <Servo.h>

// ── Servo ────────────────────────────────────────────────
Servo steeringServo;
#define SERVO_PIN    9
#define SERVO_CENTER 93
#define SERVO_LEFT   46
#define SERVO_RIGHT  140

// ── Motor ────────────────────────────────────────────────
#define ENA  12
#define IN1  11
#define IN2  10
#define SPEED_FULL  200

// ── Ultrasónicos ─────────────────────────────────────────
#define TRIG_L  24
#define ECHO_L  22
#define TRIG_R  50
#define ECHO_R  52

// ── Configuración ────────────────────────────────────────
#define CORNER_DIST        92  // cm - pared lejos = esquina detectada
#define MIN_TURN_TIME_CCW  875  // ms - giro izquierda CCW
#define MIN_TURN_TIME_CW   875  // ms - giro derecha CW
#define CORNER_COOLDOWN    1500  // ms - espera después de cada esquina
#define PING_GAP            60  // ms - separación mínima entre dos pings
                                // Solo se usa antes de saber la dirección,
                                // cuando aún hay que leer ambos sensores.
#define TURN_COUNT_COOLDOWN     500  // ms - espacio mínimo entre el conteo de dos giros
#define TOTAL_TURNS_TO_STOP      12  // número de giros (esquinas) antes de parar
#define STOP_DELAY_AFTER_LAST_TURN_MS 900  // ms - esperar esto después del
                                             // último giro antes de la parada total
                                             // cambia este número para ajustarlo

// ── Estado de dirección ──────────────────────────────────
enum Direction { UNKNOWN, CCW, CW };
Direction direction = UNKNOWN;

unsigned long lastCornerTime = 0;
unsigned long lastTurnCountTime = 0;
int turnCount = 0;
bool deadStopped = false;

// ─────────────────────────────────────────────────────────
//  Leer distancia ultrasónica (cm)
// ─────────────────────────────────────────────────────────
float readDistance(int trigPin, int echoPin) {
  digitalWrite(trigPin, LOW);
  delayMicroseconds(2);
  digitalWrite(trigPin, HIGH);
  delayMicroseconds(10);
  digitalWrite(trigPin, LOW);
  long duration = pulseIn(echoPin, HIGH, 30000);
  if (duration == 0) return 999;
  float dist = duration * 0.034 / 2.0;
  if (dist > 400) return 999;
  return dist;
}

// ─────────────────────────────────────────────────────────
//  Control de motor
// ─────────────────────────────────────────────────────────
void driveForward() {
  analogWrite(ENA, SPEED_FULL);
  digitalWrite(IN1, HIGH);
  digitalWrite(IN2, LOW);
}

void stopMotor() {
  digitalWrite(ENA, LOW);
  digitalWrite(IN1, LOW);
  digitalWrite(IN2, LOW);
}

// ─────────────────────────────────────────────────────────
//  Ejecutar giro en esquina - por tiempo puro, SIN bucle while
// ─────────────────────────────────────────────────────────
void doTurn(int servoAngle, int turnTime) {
  Serial.println("ESQUINA DETECTADA - GIRANDO!");
  steeringServo.write(servoAngle);
  driveForward();
  delay(turnTime);
  steeringServo.write(SERVO_CENTER);
  lastCornerTime = millis();

  // ── Contador de giros/vueltas ─────────────────────────
  if (millis() - lastTurnCountTime > TURN_COUNT_COOLDOWN) {
    turnCount++;
    lastTurnCountTime = millis();
    Serial.print("CONTEO DE GIROS: ");
    Serial.println(turnCount);

    if (turnCount >= TOTAL_TURNS_TO_STOP) {
      delay(STOP_DELAY_AFTER_LAST_TURN_MS);
      stopMotor();
      steeringServo.write(SERVO_CENTER);
      deadStopped = true;
      Serial.println("PARADA TOTAL - se alcanzó el conteo de giros");
    }
  }

  delay(300);
}

// ─────────────────────────────────────────────────────────
//  Configuración
// ─────────────────────────────────────────────────────────
void setup() {
  steeringServo.attach(SERVO_PIN);
  steeringServo.write(SERVO_CENTER);
  delay(1000);

  Serial.begin(9600);

  pinMode(ENA, OUTPUT);
  pinMode(IN1, OUTPUT);
  pinMode(IN2, OUTPUT);
  stopMotor();

  pinMode(TRIG_L, OUTPUT); pinMode(ECHO_L, INPUT);
  pinMode(TRIG_R, OUTPUT); pinMode(ECHO_R, INPUT);

  Serial.println("WRO 2026 - Final Open Challenge");
  Serial.println("Arrancando en 5 segundos...");
  delay(5000);
  Serial.println("ARRANCA!");
}

// ─────────────────────────────────────────────────────────
//  Bucle principal
// ─────────────────────────────────────────────────────────
void loop() {

  // ── Parada total - detiene para siempre después de TOTAL_TURNS_TO_STOP ──
  if (deadStopped) {
    return;  // ya está parado, no hace nada más
  }

  float distL = 999;
  float distR = 999;

  // ── Lectura de sensores - nunca dos pings seguidos ───
  if (direction == UNKNOWN) {
    // Dirección aún no fijada: se necesitan ambos sensores, pero
    // espaciados para que el primer ping muera antes de que dispare el segundo.
    distL = readDistance(TRIG_L, ECHO_L);
    delay(PING_GAP);
    distR = readDistance(TRIG_R, ECHO_R);

    Serial.print("I:"); Serial.print(distL);
    Serial.print(" D:"); Serial.println(distR);
  }
  else if (direction == CCW) {
    // Solo se activa el sensor IZQUIERDO. El DERECHO está apagado.
    distL = readDistance(TRIG_L, ECHO_L);

    Serial.print("I:"); Serial.print(distL);
    Serial.println(" D:OFF");
  }
  else {  // CW
    // Solo se activa el sensor DERECHO. El IZQUIERDO está apagado.
    distR = readDistance(TRIG_R, ECHO_R);

    Serial.print("I:OFF");
    Serial.print(" D:"); Serial.println(distR);
  }

  bool cooldownOk = (millis() - lastCornerTime > CORNER_COOLDOWN);

  if (direction == UNKNOWN) {
    if (cooldownOk && distL > CORNER_DIST) {
      direction = CCW;
      Serial.println("DIRECCION: CCW");
      doTurn(SERVO_LEFT, MIN_TURN_TIME_CCW);
    }
    else if (cooldownOk && distR > CORNER_DIST && distR < 400) {
      direction = CW;
      Serial.println("DIRECCION: CW");
      doTurn(SERVO_RIGHT, MIN_TURN_TIME_CW);
    }
  }
  else if (direction == CCW) {
    if (cooldownOk && distL > CORNER_DIST ) {
      doTurn(SERVO_LEFT, MIN_TURN_TIME_CCW);
    }
  }
  else if (direction == CW) {
    if (cooldownOk && distR > CORNER_DIST ) {
      doTurn(SERVO_RIGHT, MIN_TURN_TIME_CW);
    }
  }

  if (!deadStopped) {
    steeringServo.write(SERVO_CENTER);
    driveForward();
  }
}

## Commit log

2026-07-08 Update Prototype Camera Code
2026-07-08 Update Prototype Ultrasonic Code
2026-07-08 Create Prototype Motor Test
2026-07-08 Update and rename Prototype 3 Laps Code to Prototype 3 Laps (Open Challenge) Code
2026-07-09 Update Prototype 3 Laps (Open Challenge) Code
2026-07-09 Translate initial motor test comments to Spanish
    Updated comments to include Spanish translations for clarity.
2026-08-01 Update Final Camera Code
2026-08-03 Initial commit from WRO template
    [Copy of Super Blorr-Amur (2).stl, PIPE2 (2).stl, Sizzling Habbi (3).stl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]
2026-08-25 Add credit for chassis base design (Simple Arduino RC CAR by T_Lab, Thingiverse)
2026-08-26 Add materials list
2026-08-27 Rename FrontPicture.jpg to Prototype FrontPicture.jpg
2026-08-27 Create Prototype
2026-08-27 Rename IMG_7151.HEIC to Top Picture Prototype.png
2026-08-28 Rename models/Incredible Bojo-Sango (2).stl to models/models/WRO Volt Chasis.stl
    [WRO Volt Chasis.stl]
2026-08-28 Rename models/models/WRO Volt Chasis.stl to models/WRO Volt Chasis.stl
    [WRO Volt Chasis.stl]
2026-08-28 Add Volt demo GIF to main README
2026-08-28 Rewrite main README: prototype-to-final journey, accurate hardware/software docs, lessons learned
